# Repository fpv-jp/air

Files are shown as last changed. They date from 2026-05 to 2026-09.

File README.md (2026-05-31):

# Rocket Style FPV Drone

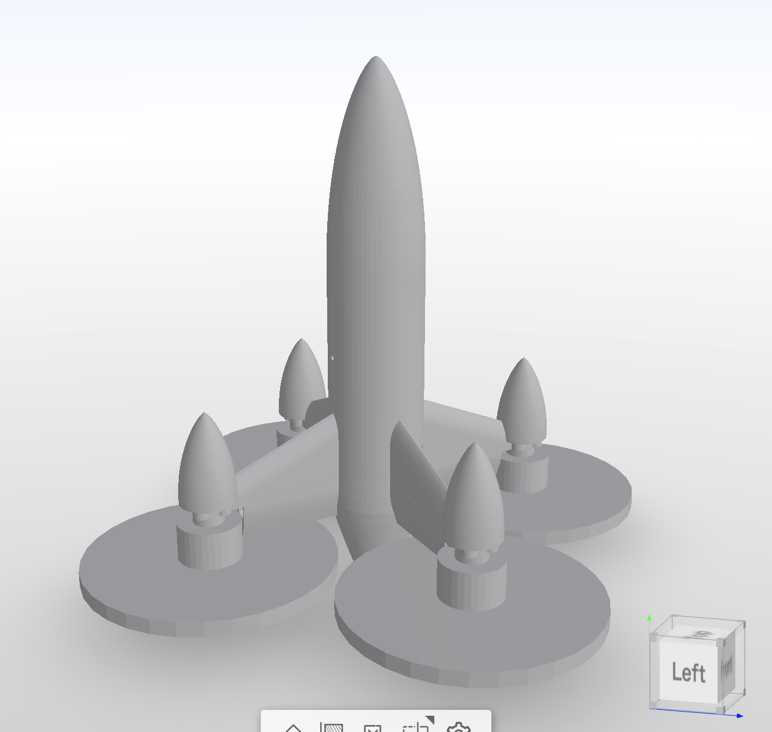
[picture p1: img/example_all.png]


## 概要

6インチFPVドローンのフレームをコードから生成するプロジェクトです。

フレームは以下の2種類のパーツで構成されています:

- **Airframe** (3Dプリンター製): TOP / MIDDLE / BOTTOM の3部位
- **Structure** (CNCルーター製 CFRP): ARM × 4 / CENTER PLATE × 2 (TOP/BOTTOM)

### Airframe

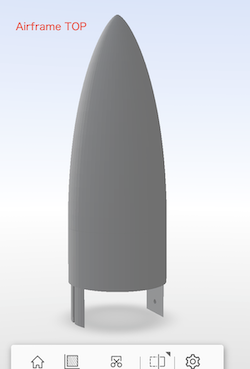
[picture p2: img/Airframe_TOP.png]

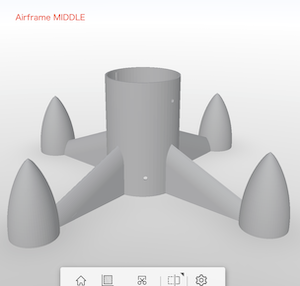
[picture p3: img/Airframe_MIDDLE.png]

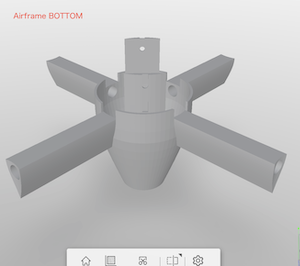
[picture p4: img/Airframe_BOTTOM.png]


### Structure

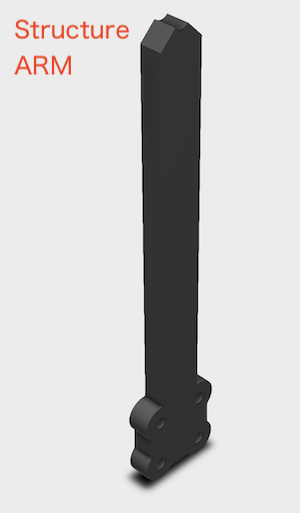
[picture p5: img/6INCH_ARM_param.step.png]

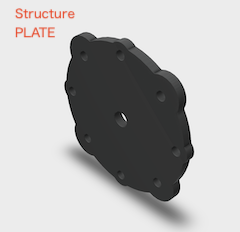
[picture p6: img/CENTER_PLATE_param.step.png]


### 組み立てイメージ

電子部品などの取り付けイメージ
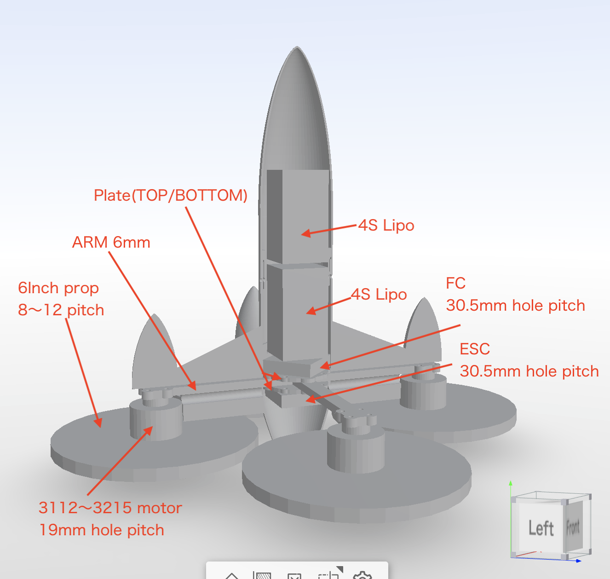
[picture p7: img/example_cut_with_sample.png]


テスト印刷時のイメージ
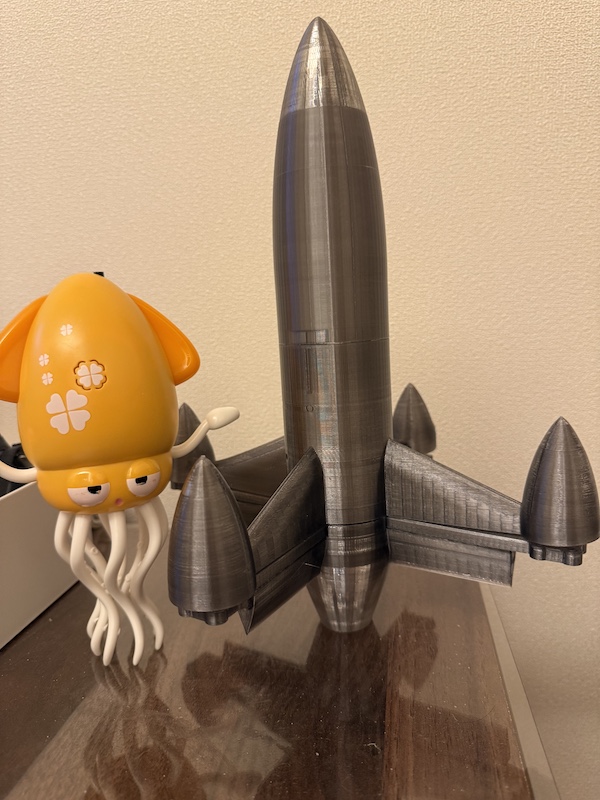
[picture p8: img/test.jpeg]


---

## ディレクトリ構成

```
.
├── base.py                 # Blender Python API ユーティリティモジュール
├── create_Airframe.py      # Airframe生成スクリプト (Blender bpy)
├── create_Structure.py     # Structure生成スクリプト (CadQuery) → STEP + G-code出力
├── generate_gcode.py       # STLからG-codeを生成するスクリプト
├── mdf/                    # 3Dプリンター用STLファイル
│   ├── Airframe_TOP.stl
│   ├── Airframe_MIDDLE.stl
│   └── Airframe_BOTTOM.stl
├── cnc/                    # CNCルーター用ファイル (STEP + G-code)
│   ├── 6INCH_ARM_param.step
│   ├── 6INCH_ARM_param.nc
│   ├── CENTER_PLATE_param.step
│   └── CENTER_PLATE_param.nc
├── example/                # サンプルスクリプト
│   └── example.py
└── img/                    # ドキュメント用画像
```

---

## Airframe (3Dプリンター)

### 必要な機材

- **3Dプリンター**: Bambu Lab A1 3D Printer
- **スライサー**: Bambu Studio

※ A1 miniだとサイズが収まらない可能性があります

### STLファイル

- [Airframe_TOP.stl](mdf/Airframe_TOP.stl)
- [Airframe_MIDDLE.stl](mdf/Airframe_MIDDLE.stl)
- [Airframe_BOTTOM.stl](mdf/Airframe_BOTTOM.stl)

### フィラメント

想定しているフィラメントはPET(G)-CFです。

- PA6-CFなどを使用する場合、印刷後にプライマーを塗布するなど吸湿対策が必須です
- 理想はPPA-CFですが、クロージャー型やノズル温度320度などの条件を満たすプリンターが必要です

---

## Structure (CNCルーター)

### 必要な機材

- **CNCルーター**: LUNYEE 3020 Nova Desktop CNC Router
- **CAMソフトウェア**: GRBLに対応したソフトウェア (公式ではUGSがサポートされています)

### 加工パラメータ

| パラメータ | 値 |
|---|---|
| 素材 | CFRP |
| ARMの厚み | 6mm |
| センタープレートの厚み | 3mm |
| エンドミル径 | 3mm (超硬2枚刃) |
| スピンドル回転数 | 15,000 RPM |
| XY送り速度 | 600 mm/min |
| Z送り速度 | 120 mm/min |
| 切り込み深さ | 0.5 mm/pass |

> ⚠️ CFRPの粉塵は有害です。集塵装置の使用とN95マスクの着用が必須です。

### NCファイル (G-code)

- [6INCH_ARM_param.nc](cnc/6INCH_ARM_param.nc)
- [CENTER_PLATE_param.nc](cnc/CENTER_PLATE_param.nc)

### STEPファイル

- [6INCH_ARM_param.step](cnc/6INCH_ARM_param.step)
- [CENTER_PLATE_param.step](cnc/CENTER_PLATE_param.step)

---

## カスタマイズ

### Airframe (Blender Python API)

Airframeの生成には[Blender Python API (bpy)](https://docs.blender.org/api/current/index.html)を使用しています。
モデリングをしなくても、Pythonスクリプトを実行するだけでモデルが生成されます。

#### 使い方

1. Blenderのスクリプティングワークスペースから下記のファイルを開きます

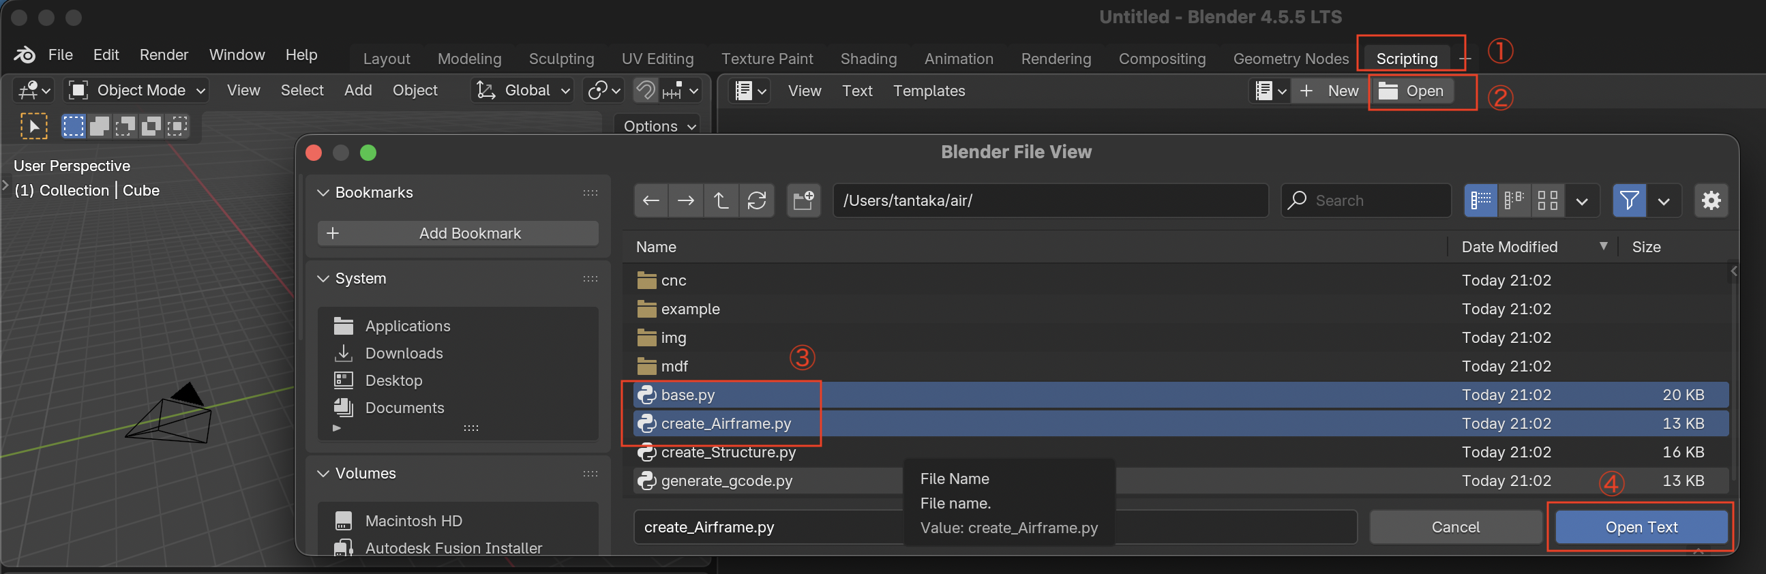
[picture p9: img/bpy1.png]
   

   - [base.py](base.py) — ユーティリティモジュール
   - [create_Airframe.py](create_Airframe.py) — メインスクリプト

   2枚開いている内の `create_Airframe.py` を選択します

   

2. 作成したい部位の `False` をコメントアウトして実行します

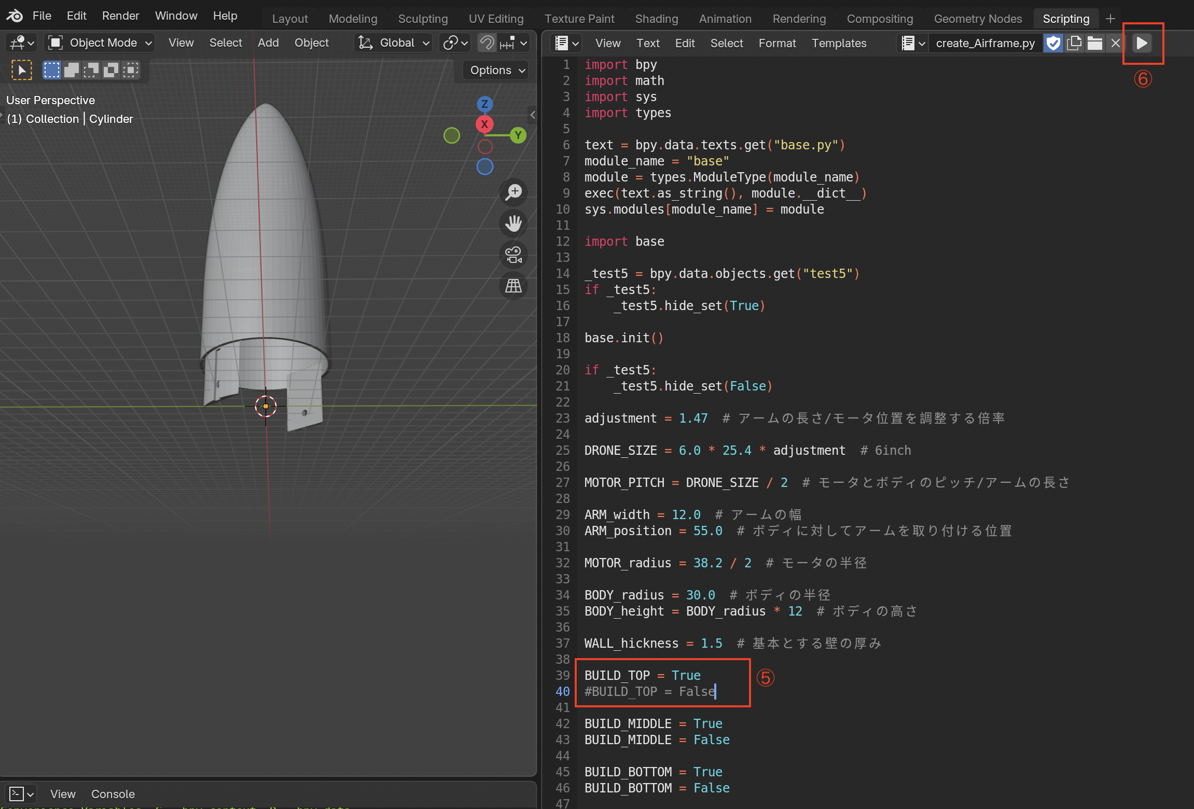
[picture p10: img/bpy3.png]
   

   例: BOTTOMを作成したい場合

   

### Structure (CadQuery)

Structureの生成には[CadQuery](https://cadquery.readthedocs.io/)を使用しています。
`create_Structure.py` を実行すると、STEPファイルとG-codeが同時に生成されます。

```bash
python create_Structure.py
```

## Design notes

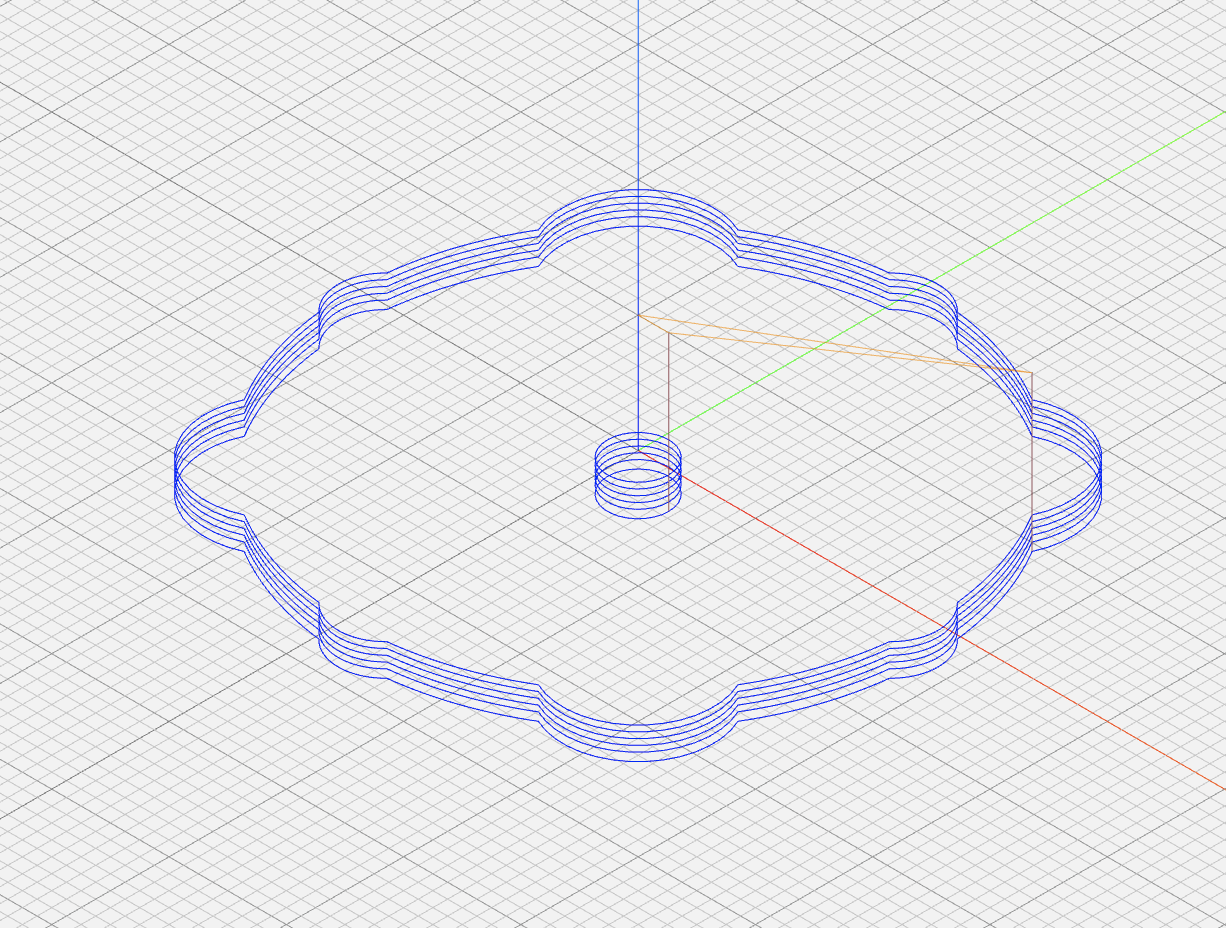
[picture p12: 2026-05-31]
img/CENTER_PLATE_param.nc.png

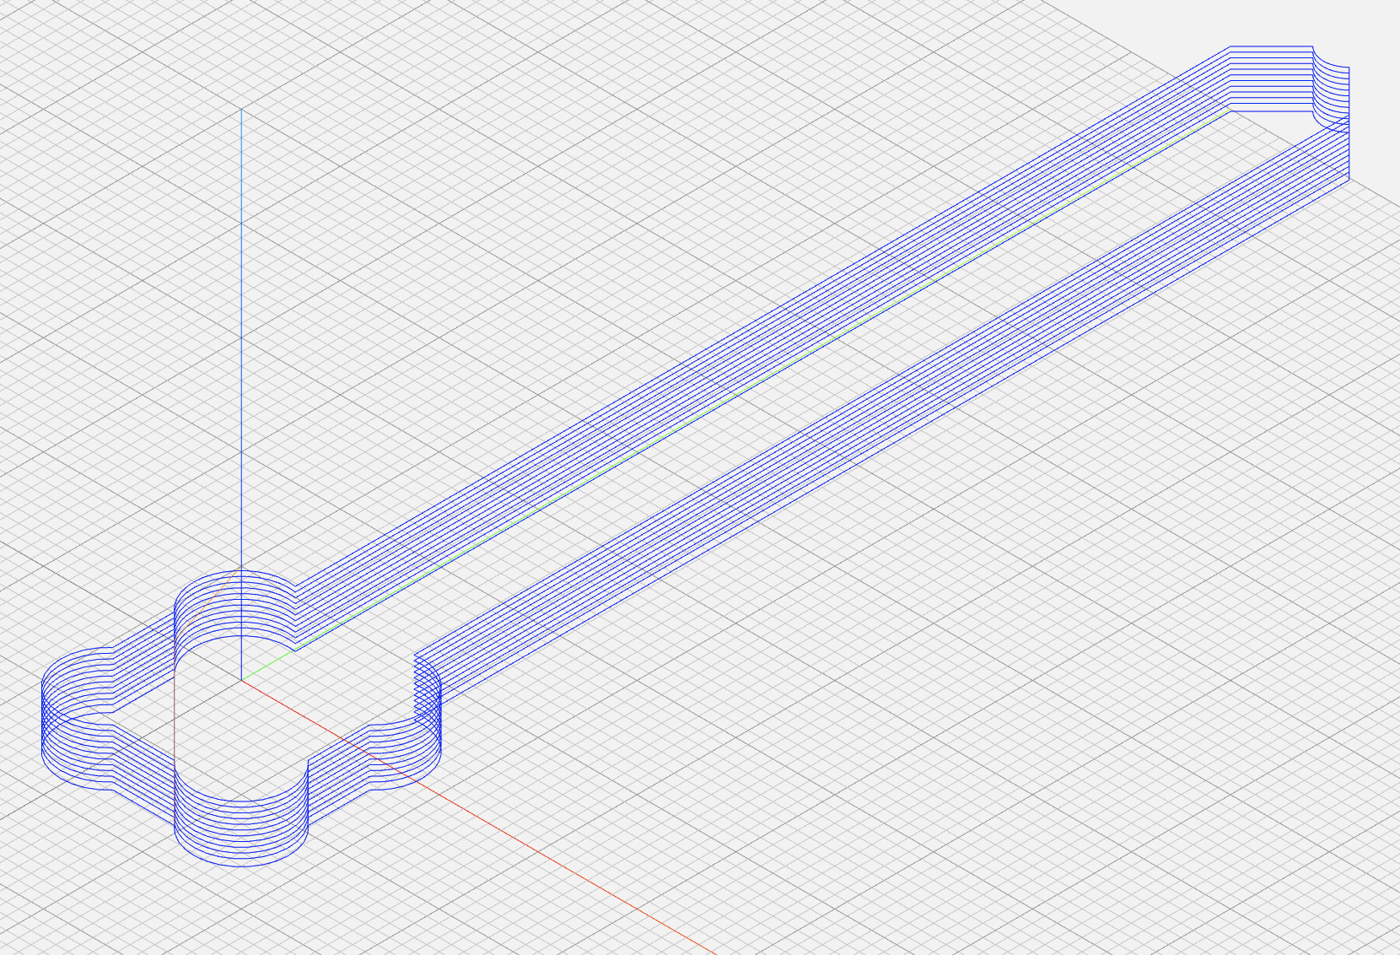
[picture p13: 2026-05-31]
img/6INCH_ARM_param.nc.png

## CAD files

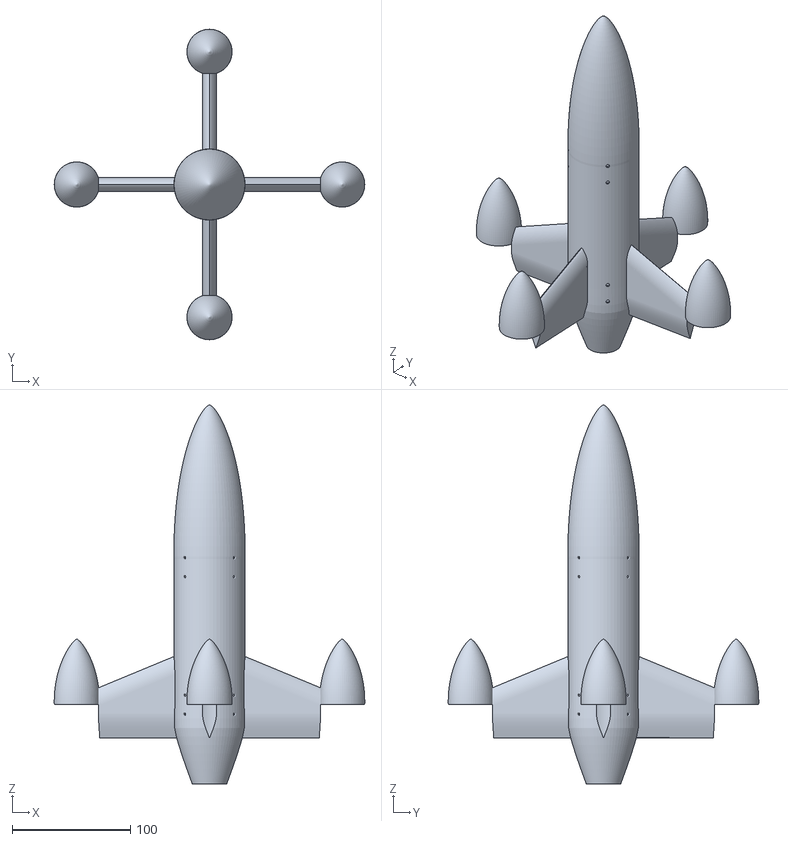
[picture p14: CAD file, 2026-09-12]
example2/main.stl
262.2 x 262.2 x 320.0

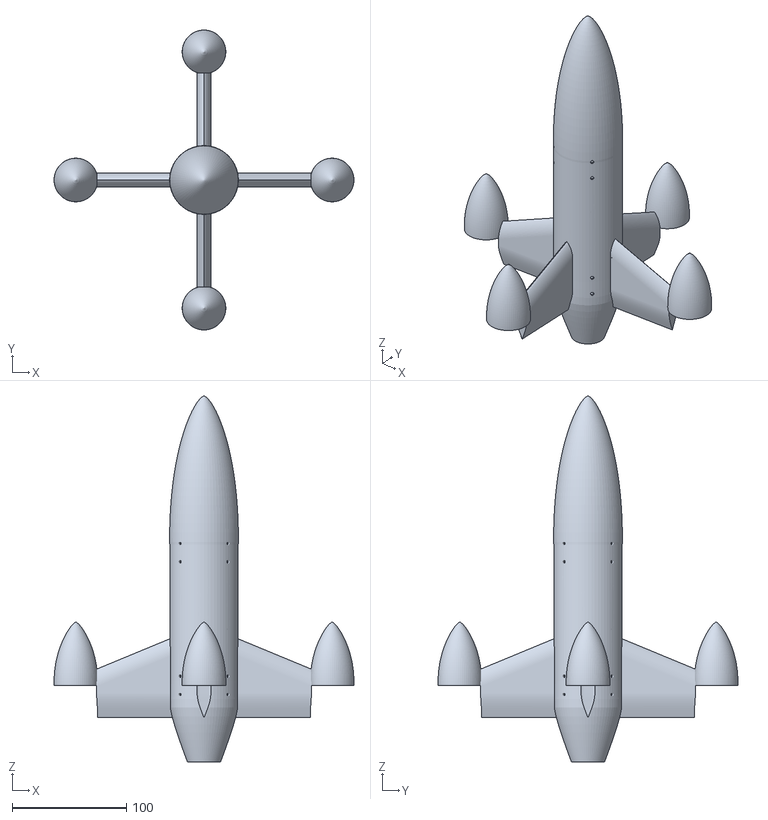
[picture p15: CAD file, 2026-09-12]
example2/main_fixed.stl
262.2 x 262.2 x 320.0

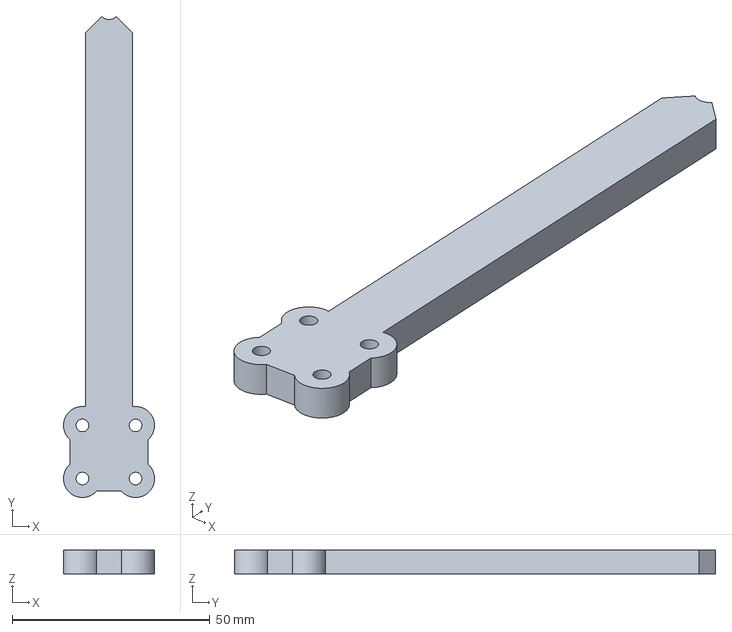
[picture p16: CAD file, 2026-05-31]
cnc/6INCH_ARM_param.step
23.0 x 121.7 x 6.00 mm

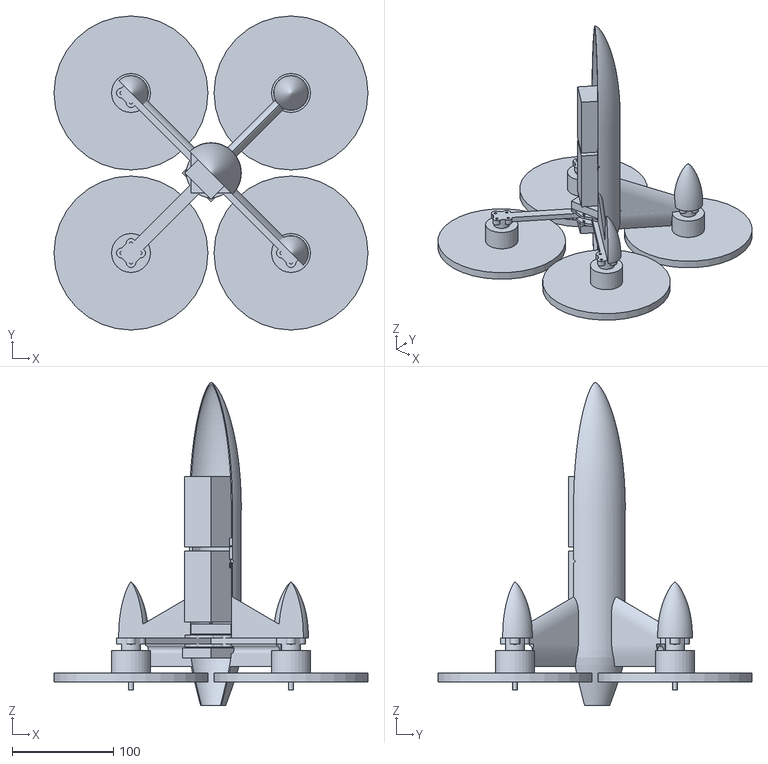
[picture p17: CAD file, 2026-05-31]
example/example_cut_with_sample.stl
310.8 x 310.8 x 320.0

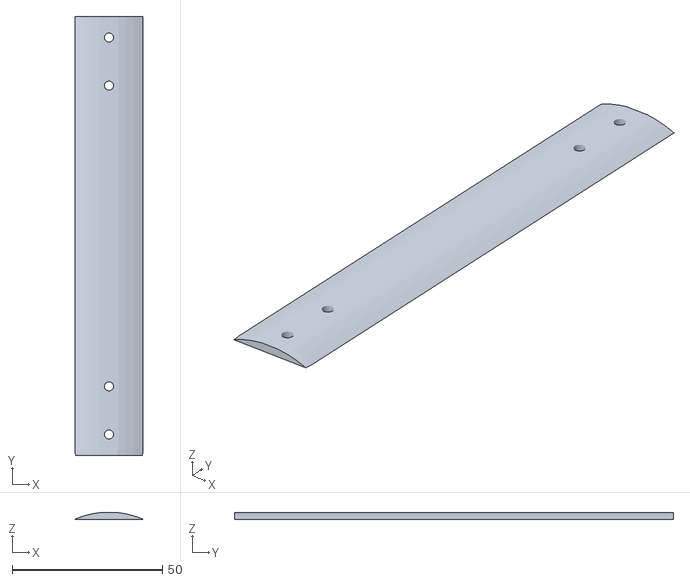
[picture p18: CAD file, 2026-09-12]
example2/part.stl
22.7 x 146.0 x 2.20

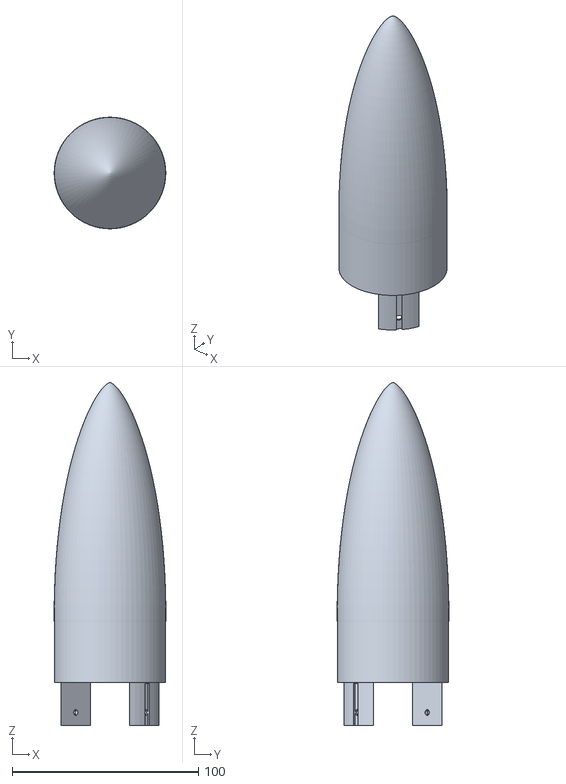
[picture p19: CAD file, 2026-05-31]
mdf/Airframe_TOP.stl
59.9 x 59.9 x 184.0

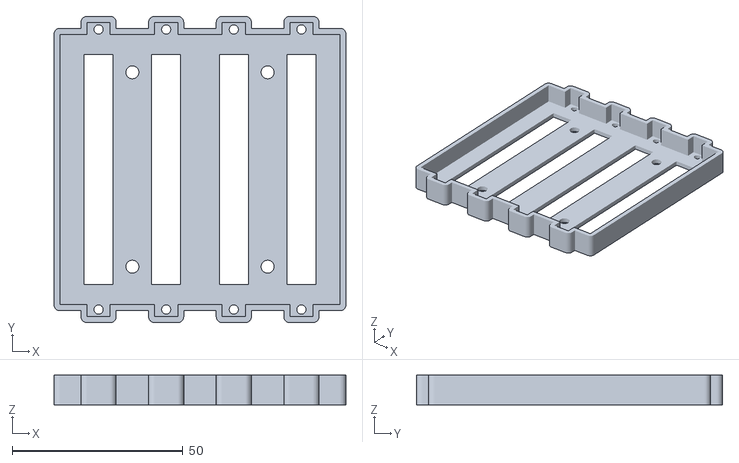
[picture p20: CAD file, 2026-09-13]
other/battery_.stl
85.5 x 89.7 x 8.75

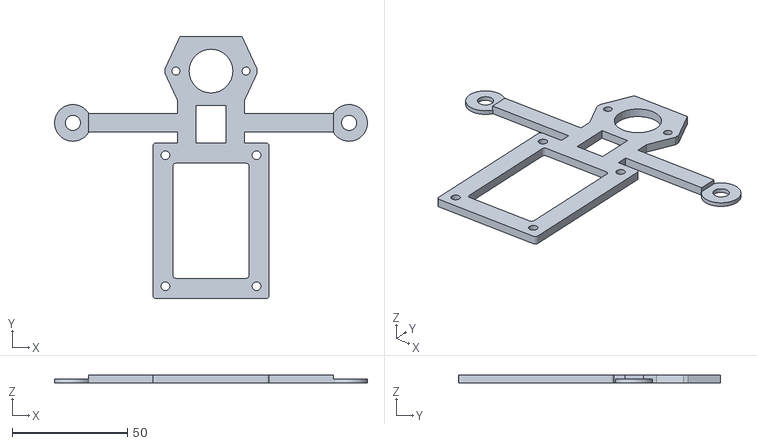
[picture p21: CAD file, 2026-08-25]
raspi/cm4-c-mount2.stl
136.0 x 113.8 x 3.50

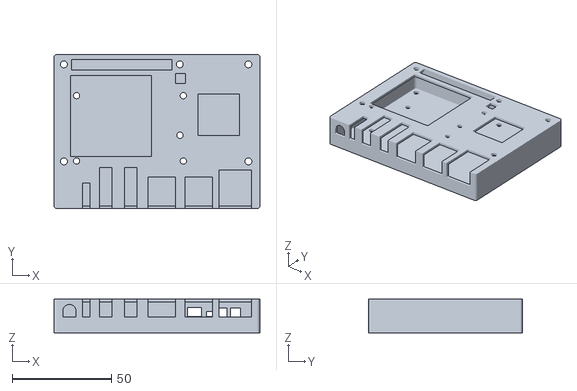
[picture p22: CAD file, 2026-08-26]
rock5/rock5b.stl
104.0 x 78.0 x 17.0

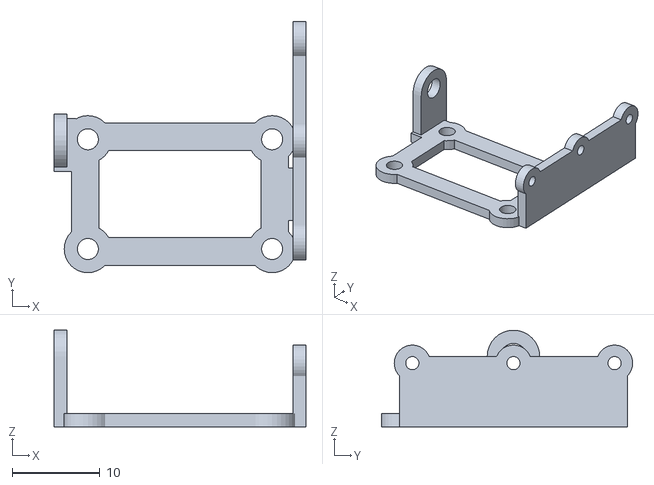
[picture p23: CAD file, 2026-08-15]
servo/FS0403-mount.stl
28.7 x 28.6 x 11.0

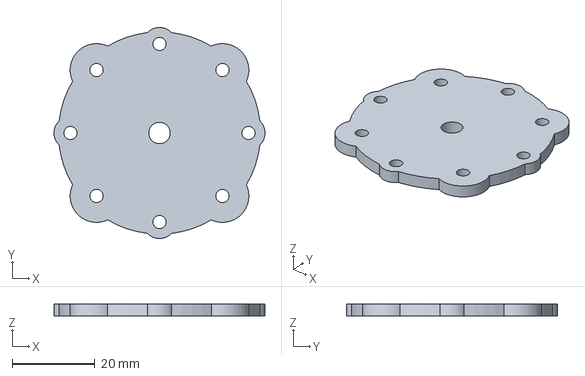
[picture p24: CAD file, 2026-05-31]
cnc/CENTER_PLATE_param.step
51.1 x 51.1 x 3.00 mm

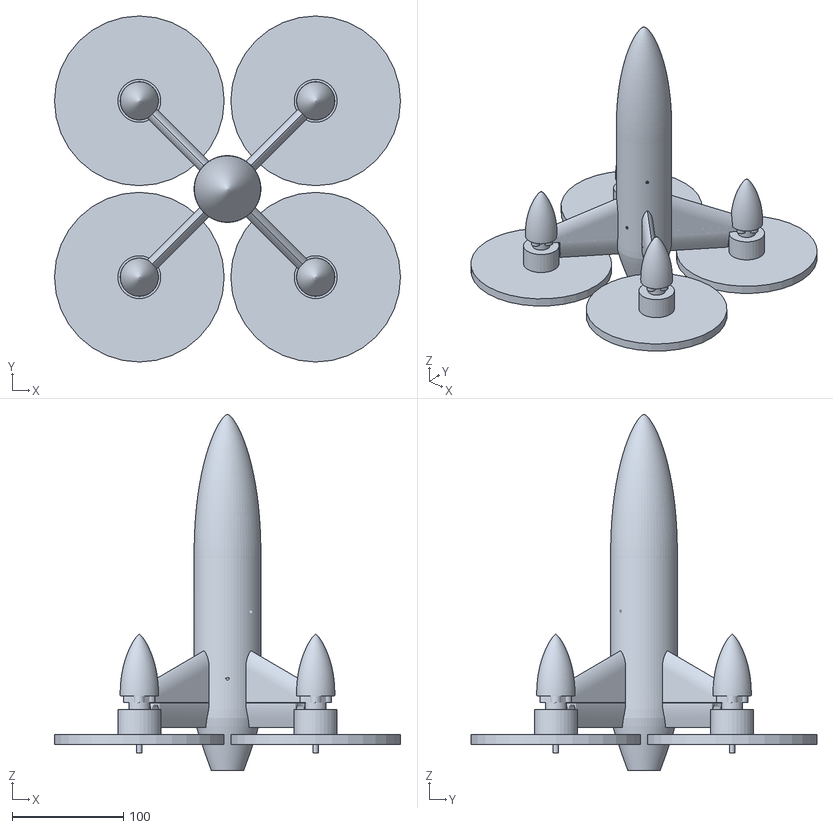
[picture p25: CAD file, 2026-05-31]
example/example_all.stl
310.8 x 310.8 x 320.0

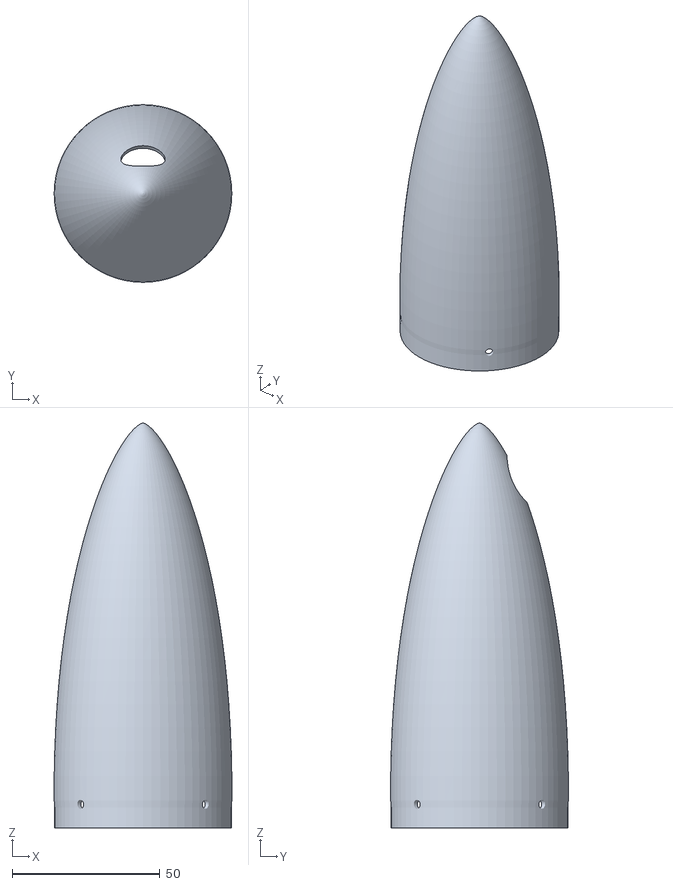
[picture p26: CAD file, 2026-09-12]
example2/top.stl
60.1 x 60.1 x 137.0

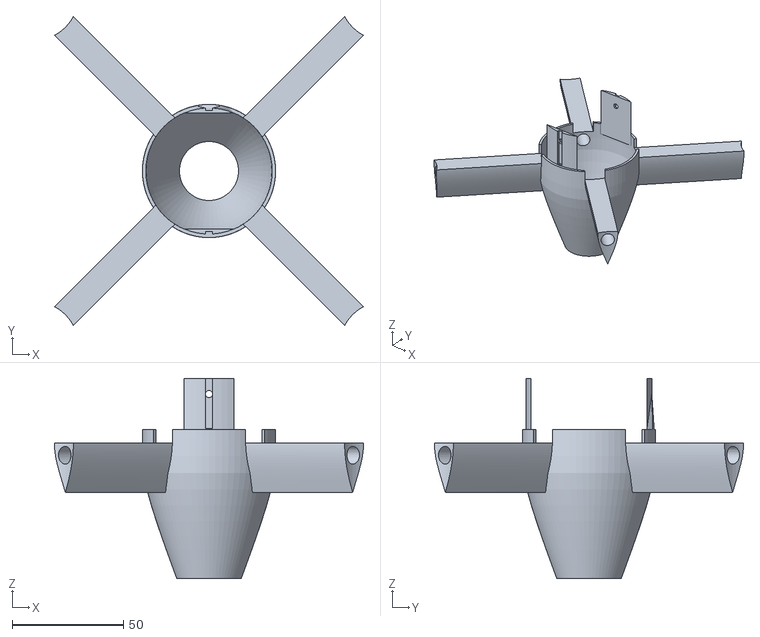
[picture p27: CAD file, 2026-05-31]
mdf/Airframe_BOTTOM.stl
139.0 x 139.0 x 90.0

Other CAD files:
other/bms.stl
raspi/cm4-c-wifi.stl
servo/FS0403.stl
example2/middle_fixed.stl
example2/bottom.stl
example2/bottom_fixed.stl
example2/middle.stl
example2/top_fixed.stl
mdf/Airframe_MIDDLE.stl
other/battery.stl
raspi/camera-mx415_fixed.stl
raspi/cm4-b.stl
raspi/cm4-c-mount.stl
raspi/cm4-c-ubec.stl
raspi/cm5-a.stl
raspi/cm5-b.stl
servo/SG90.stl
servo/antenna.stl
servo/monitor.stl

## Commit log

2026-08-28 1てｓｔ
2026-09-05 ああああ
    [example_all.stl, example_cut.stl, example_cut_with_sample.stl]
2026-09-13 tえst
    [battery_.stl]
